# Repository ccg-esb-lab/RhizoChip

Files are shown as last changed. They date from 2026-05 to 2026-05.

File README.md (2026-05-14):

# RhizoChip

**RhizoChip: A modular 3D-printable in situ co-culture device for studying microbial interactions in soil and plant-associated systems**

## Overview

RhizoChip is a modular 3D-printable device designed for the controlled co-culture of microbial communities under laboratory and soil-associated conditions.

The device allows spatial confinement of microbial populations while enabling the exchange of diffusible metabolites through permeable membranes. This architecture supports the study of microbial interactions, community assembly, and the identification of functional consortia with potential applications in sustainable agriculture.

The design is implemented as a parametric OpenSCAD model, allowing users to modify the number of modules, rows, wells, dimensions, ports, and other structural features directly from code.

## Repository contents

- [`scad/`](scad/)  
  Parametric OpenSCAD design files used to generate the device geometry.

- [`stl/`](stl/)  
  Exported STL files for selected device configurations.

- [`docs/`](docs/)  
  Technical documentation describing the design, fabrication workflow, validation stage, and intended applications of the device.

## Documentation

The full technical report can be found in [`RhizoChip_TechnicalDocument.pdf`](./docs/RhizoChip_TechnicalDocument.pdf).

## Authors

Systems Biology Lab, Center for Genomic Sciences, UNAM.
Carles Tardío Pi and Rafael Peña-Miller.

## License

This project is licensed under the MIT License for code and documentation. Hardware design files are licensed under the CERN Open Hardware License. See the [`license.txt`](license.txt) file for details.

## Acknowledgements

We thank past and present members of the Systems and Synthetic Biology laboratories at CCG-UNAM for their input, discussion, and experimental support.

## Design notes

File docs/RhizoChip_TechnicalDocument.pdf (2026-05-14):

# RhizoChip // Technical Documentation

Version: 0.1
Last updated: May 2026
Contributors: RhizoChip is developed by the Systems Biology Program at the Center for Genomic Sciences, UNAM, as part of an effort to build reproducible, open, and modular experimental pipelines for microbial ecology and experimental evolution.
Development: Carles Tardío Pi (tardiopi@ccg.unam.mx), Rafael Peña Miller (rpm@ccg.unam.mx) Experimental users and contributors: Nicole Gomez, Gustavo Cuaxinque, Andrés López, Esperanza Martinez, Ayari Fuentes

License: RhizoChip is intended as an open research tool. Unless stated otherwise, the source code is distributed under the MIT License. The documentation, diagrams, and written material are distributed under a Creative Commons Attribution 4.0 International License (CC BY 4.0). Users may use, modify, and redistribute the code and documentation, provided that appropriate credit is given to the original contributors.

## 1. Overview

This device is a modular experimental platform designed for the controlled co-culture of microbial communities under laboratory and environmentally relevant conditions. The system enables the spatial confinement of microbial populations while allowing the exchange of diffusible metabolites and chemical signals through permeable membranes. It is intended for the study of microbial interactions, community assembly, and functional performance of synthetic microbial consortia, with a particular focus on soil and plant-associated microbiomes.

The platform is being developed as a tool to support the identification and optimization of microbial consortia with potential applications in sustainable agriculture, including biofertilization, plant growth promotion, and soil health improvement.

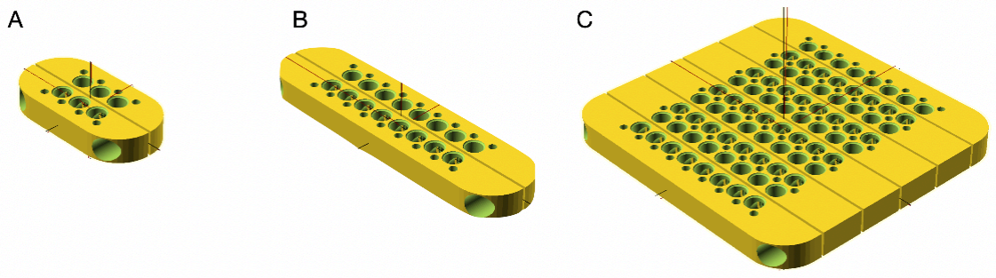
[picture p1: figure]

Figure 1. Modular architecture of the microbial co-culture device.
(A) 3D render of a miniaturized configuration with two modules and three rows of paired compartments.
(B) 3D render of a two-module configuration containing eight pairs of connected wells, designed for parallel co-culture assays. (C) 3D render of an expanded modular configuration composed of five paired module sets, each containing eight rows, illustrating the scalability of the device for larger experimental designs.

## 2. Design Principle

The device consists of modular rows of compartments that can be connected in paired configurations (Figure 1). Each compartment is designed to contain a microbial isolate or a defined microbial community. Adjacent compartments are separated by permeable membranes, allowing the diffusion of metabolites and chemical signals while preventing direct physical mixing of populations.

This architecture enables controlled comparison between connected and isolated configurations. In this way, the system can distinguish interaction-mediated effects from autonomous growth dynamics.

The design is implemented as a parametric OpenSCAD model, which allows the geometry of the device to be modified directly from code. Key parameters include the number of modules, number of rows and columns, module dimensions, well diameter, well spacing, lateral ports, screw holes, rod channels, lid geometry, and label placement. This makes the platform adaptable to different experimental scales, from small interaction assays to larger multi-module screens.

The modular design supports several experimental configurations, including:

- paired compartments for testing direct interaction effects
- multiple connected rows for higher-throughput interaction screening
- isolated rows as non-interaction controls
- expanded multi-block systems for larger community designs
- separate body and lid components for assembly, containment, and handling

## 3. Fabrication and Digital Design Workflow

The device is generated from a parametric OpenSCAD script. The code produces the 3D geometry of the device body and lid, and allows users to select between different configurations by editing the parameter block at the beginning of the file. For example, the user can define the number of modules, the number of rows, the number of columns, and the overall module dimensions.

The script includes predefined configurations, such as compact two-module devices, larger two-module devices with multiple rows, and multi-module layouts. The user can also define custom geometries by modifying the relevant parameters. The model includes integrated features for wells, lateral ports, vertical screw holes, horizontal rod channels, rounded module edges, and engraved labels.

A typical workflow is:

1. Open the .scad file in OpenSCAD.
2. Select whether to render the body or the lid using the render_body and render_lid variables.
3. Choose or modify the desired device configuration by setting parameters such as N, nrows, ncols, module_length, and module_width.
4. Preview and render the model.
5. Export the resulting geometry as an STL file.
6. Slice the STL file using standard 3D-printing software.
7. Fabricate the component using extrusion-based 3D printing.

Initial prototypes have been fabricated using 3D printing, primarily through extrusion-based additive manufacturing (Figure 2). This approach enables rapid prototyping, iterative design modifications, and low-cost production of custom geometries.

The current designs include devices fabricated in PLA and PC. Future optimization will focus on material compatibility with soil conditions, mechanical stability, sterilization procedures, membrane integration, and reproducibility across printing batches. The same digital design workflow can be adapted to other materials or manufacturing methods depending on the intended application and required robustness.

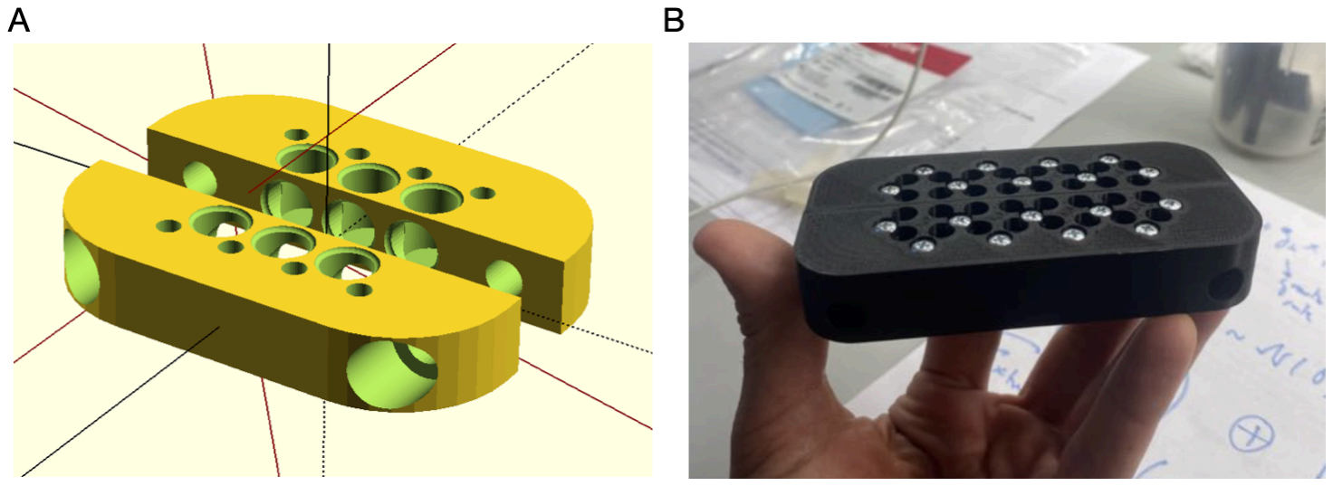
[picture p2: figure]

Figure 2. Design and fabrication of the microbial co-culture device.
(A) 3D render of a module with three compartments connected in paired configurations, allowing metabolite exchange between adjacent units. (B) Prototype of the device fabricated by 3D printing.

## 4. Experimental Use

The device is designed for use in several experimental contexts:

1. Laboratory experiments
The system can be inoculated with defined microbial communities and incubated under controlled conditions to evaluate containment, reproducibility, and metabolite-mediated interactions.
2. Controlled soil or mesocosm assays
The device can be placed in soil-like environments, compost, or pot systems to assess microbial growth and interaction dynamics under more complex physicochemical conditions.
3. In situ agricultural testing
The device can be deployed directly in agricultural soils to evaluate microbial interactions under field-relevant conditions.

In ongoing pilot work, the device has been used with synthetic microbial communities derived from bean root-associated microbiomes. These communities are being evaluated for their potential to assemble, interact, and support functions relevant to plant productivity.

## 5. Functional Validation

The device has been evaluated through a series of validation steps designed to test its performance under controlled experimental conditions. These include:

- confirmation of physical containment between compartments
- assessment of membrane-mediated exchange
- evaluation of microbial growth inside the device
- comparison between connected and isolated configurations
- reproducibility across device replicates
- recovery of microbial samples after incubation
- functional testing of assembled consortia in plant-associated assays

Physical containment was evaluated through contamination-control experiments in which the device was exposed to external bacterial cultures while monitoring whether the internal compartments remained uncontaminated. These assays confirmed that the device maintains physical separation between populations while allowing controlled experimental handling (Figure 3).

Microbial growth and recovery were tested using defined microbial communities, including synthetic communities derived from bean root-associated microbiota. These experiments demonstrated that the device supports microbial incubation and downstream recovery of samples for analysis.

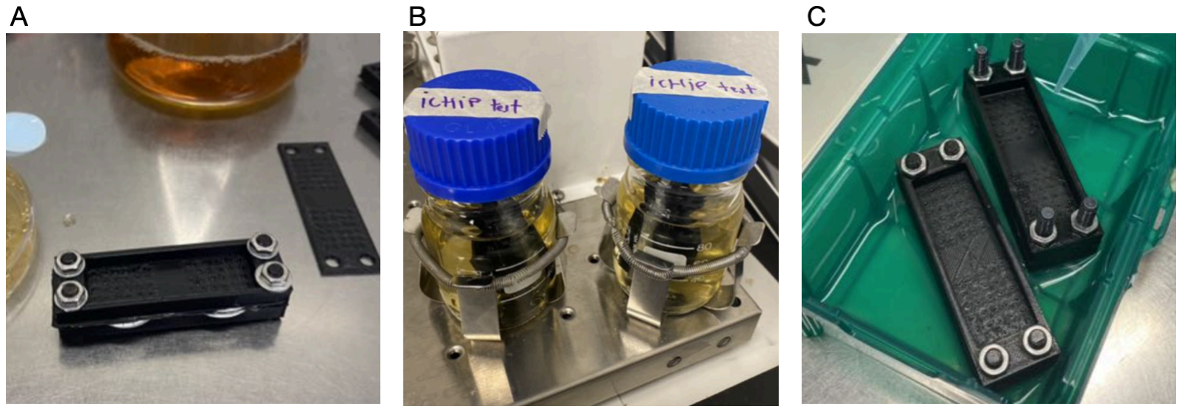
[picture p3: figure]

Figure 3. Validation of the device under controlled laboratory conditions.
(A) Co-culture device inoculated with a synthetic community derived from bean roots, composed of seven strains.
(B) Co-culture device inoculated with the same seven-strain synthetic community, used to evaluate system performance under controlled conditions. (C) Containment test in which the device was exposed to culture medium containing external bacteria. No internal contamination was observed, demonstrating physical isolation between compartments.

Functional validation is currently in progress through plant-associated assays in which assembled microbial communities are being evaluated for their effects on relevant plant phenotypes, including nodulation and growth-associated responses. This ongoing work is intended to assess the capacity of the platform to link microbial community structure and interaction patterns with functional outcomes in plant-associated systems.

## 6. Analytical Framework

The device generates quantitative data that can be used to infer microbial interactions. Growth, abundance, community composition, and functional readouts can be compared across experimental configurations.

Data analysis may include:

- comparison of growth in connected versus isolated compartments,
- inference of positive, negative, or neutral interactions,
- identification of stable consortia,
- detection of community-level functional effects,
- integration with ecological models or network inference methods.

The device is therefore not only a culture platform, but also part of an integrated experimental workflow for studying microbial interaction networks.

## 7. Technological Relevance

The platform addresses a current limitation in microbial ecology and agricultural biotechnology: the lack of experimental systems that connect controlled co-culture assays with environmentally relevant soil conditions. Existing in situ cultivation tools, such as iChip-like devices, have been useful for recovering previously uncultivable microorganisms, but are not primarily designed to quantify interaction networks among defined microbial communities.

This device aims to bridge that gap by combining:

- spatial confinement,
- controlled metabolite exchange,
- modular experimental design,
- compatibility with synthetic communities,
- potential deployment in soil or agricultural environments.

## 8. Development Stage

The current state of development corresponds to an intermediate technology readiness level, between TRL 4 and TRL 6. The system has been designed, fabricated, and tested as a functional prototype under laboratory conditions, demonstrating the basic operation of the co-culture architecture and the integration of its main components.

Current work focuses on advancing the platform from laboratory validation toward demonstration in relevant agricultural environments. This includes improving material selection, reproducibility, structural robustness, membrane integration, and performance under soil-associated conditions.

The next development phase will support the transition from TRL 4, corresponding to validation of an integrated prototype in the laboratory, toward TRL 6, corresponding to demonstration of the system in relevant agricultural settings. This will involve testing the device in controlled soil systems, mesocosms, and field-like conditions to evaluate its performance, reliability, and capacity to generate reproducible data on microbial interactions in soil.

## 9. Intended Applications

Potential applications include:

- identification of microbial consortia for sustainable agriculture,
- screening of plant-associated microbial communities,
- evaluation of biofertilizer or bioprotective formulations,
- study of microbial interaction networks in soil,
- development of microbiome-based agricultural technologies,
- experimental validation of synthetic microbial communities.

## 10. Conclusion

The in situ microbial co-culture device provides a modular and adaptable platform for studying microbial interactions under controlled and environmentally relevant conditions. By enabling spatial confinement and metabolite exchange, the system supports the quantitative analysis of microbial interactions and the identification of functional consortia.

Its development has potential relevance for agricultural biotechnology, particularly for the rational design and validation of microbial consortia aimed at improving productivity and sustainability in agricultural systems.

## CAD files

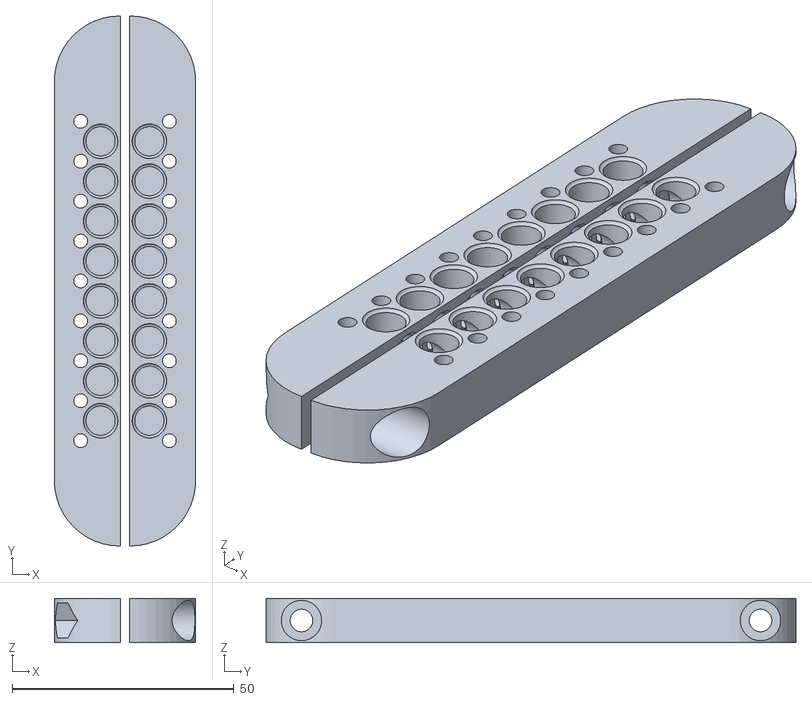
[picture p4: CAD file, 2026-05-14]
stl/RhizoChip.stl
31.9 x 119.5 x 10.0

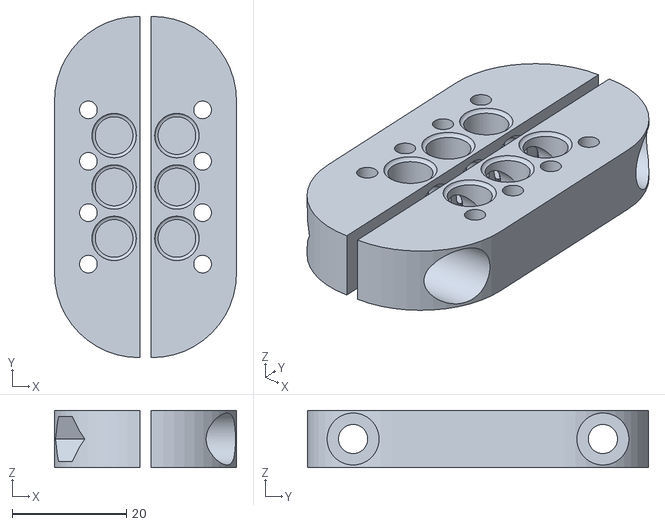
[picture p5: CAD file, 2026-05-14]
stl/RhizoChip_mini.stl
31.9 x 59.8 x 10.0

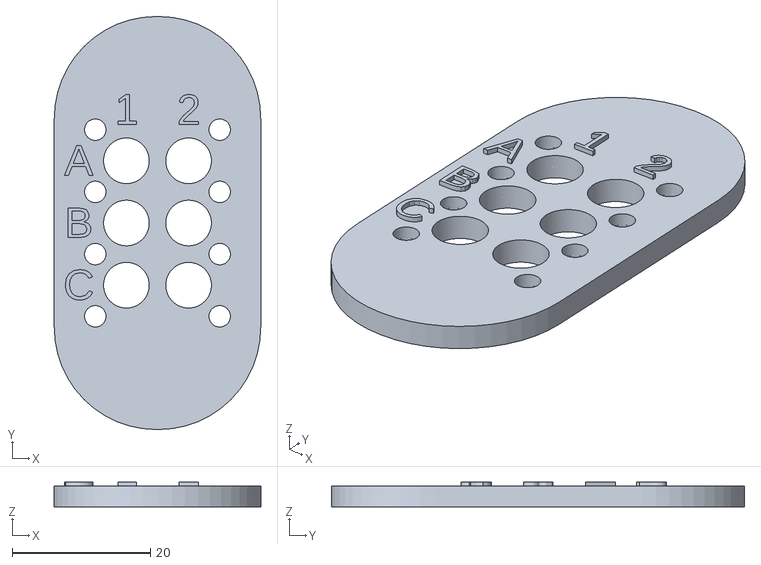
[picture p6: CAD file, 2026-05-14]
stl/RhizoChip_mini_lid.stl
29.9 x 59.8 x 3.61

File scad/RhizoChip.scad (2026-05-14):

// -----------------------------------------------------------------------------
// RhizoChip: Modular co-culture device generator
// -----------------------------------------------------------------------------
// Parametric OpenSCAD design for modular microbial co-culture devices.
// The model includes configurable module size, well layout, lateral ports,
// fastening features, lids, and label placement.
//
// Developed by ESB / Center for Genomic Sciences, UNAM
//
// This code is released under the MIT License.
// See the LICENSE file distributed with this source code for details.
//--------------------------------------------
// PRINTING / RENDER PARAMETERS
//--------------------------------------------

render_body = false;
render_lid  = true;

gap = 0.0;
fn  = 48;

//--------------------------------------------
// ARRAY / DEVICE CONFIGURATION
//--------------------------------------------

plate_length = 119.5;

// Version: Bimodule mini (2-cols, 3 rows)
/*
N = 2;      // Number of modules
nrows = 3;  // Number of rows
ncols = 2;  // Number of columns
module_length=plate_length/2;
module_width=plate_length/4/2;
label_margin_top  = 13.5;
*/

// Version: Bimodule (2-cols, 8 rows)

N = 2;      // Number of modules
nrows = 8;  // Number of rows
ncols = 2;  // Number of columns
module_length=plate_length;
module_width=plate_length/4/2;
label_margin_top  = 20;


// Version: Multimodule (2-cols, 8 rows)
/*
N = 6;      // Number of modules
nrows = 8;  // Number of rows
ncols = 2;  // Number of columns
module_length=plate_length;
module_width=18;
label_margin_top  = 20;
*/

// Version: Multimodule mini (2-cols, 3 rows)
/*
N = 4;      // Number of modules
nrows = 5;  // Number of rows
ncols = 2;  // Number of columns
module_length=18.4*4;
module_width=18.4;
label_margin_top  = 10;
*/

//--------------------------------------------
// MODULE DIMENSIONS
//--------------------------------------------


module_h   = 10;   // Body height (mm)
lid_h     = 3;    // Lid height (mm)
bottom_th = 1.2;  // Solid bottom thickness (mm)

//--------------------------------------------
// WELL GRID
//--------------------------------------------

pitch_x = 9.0;  // Well pitch along X (mm)
pitch_y = 9.0;  // Well pitch along Y (mm)

//--------------------------------------------
// WELL GEOMETRY
//--------------------------------------------

well_d = 6.6;       // Well diameter (mm)
well_r = well_d/2;  // Well radius (mm)

label_margin_left = 3.5;

//--------------------------------------------
// HARDWARE GEOMETRY
//--------------------------------------------

r_oring = 0.6;   // O-ring radius (mm)
r_screw = 1.55;  // Vertical screw hole radius (mm)
r_rod   = 2.55;  // Horizontal rod radius (mm)

h_bolt        = 12.5;   // Bolt head recess height (mm)
h_bolt_bottom = -0.01;  // Bottom bolt recess height (mm)
r_bolt_bottom = 3.2;    // Bottom bolt-hole radius (mm)

d_rod      = 8.0;   // Rod offset from edge (mm)
r_rod_bolt = 4.55;  // Rod bolt radius (mm)


//--------------------------------------------
// ROUNDING / CORNER GEOMETRY
//--------------------------------------------

corner_r = 14.75;
box_padding = 20.0;
diameter_round = (module_length + box_padding) / 3.372;
corner_d       = (module_length + box_padding) / 3.372;

//--------------------------------------------
// DEFAULT ALIASES FOR MODULE PARAMETERS
//--------------------------------------------

default_gap      = gap;
default_fn       = fn;

default_corner_d = corner_d;
default_corner_r = corner_r;

// DEFAULT HARDWARE PARAMETERS
default_r_rod     = r_rod;
default_d_rod     = d_rod;
default_r_bolt    = r_bolt_bottom;
default_h_bolt    = h_bolt;
default_r_screw   = r_screw;

default_slop      = 2;
default_fn_bolt   = 6;

// DEFAULT WELL GRID PARAMETERS
default_rows      = nrows;
default_cols      = ncols;
default_pitch_x   = pitch_x;
default_pitch_y   = pitch_y;
default_r_well    = well_r;
default_bottom_th = bottom_th;
default_lid_depth = 1;

// DEFAULT LABEL PARAMETERS
default_label_font  = "Liberation Sans";
default_label_size  = 0.5 * default_pitch_y;
default_label_depth = 0.6;
default_margin_left = label_margin_left; 
default_label_margin_top  = label_margin_top;

//--------------------------------------------
// MODEL ASSEMBLY
//--------------------------------------------

if (render_body) {

    stack_modules_with_cuts(
        n         = N,
        L         = module_width,
        W         = module_length,
        H         = module_h,
        gap       = default_gap,
        total_len = undef,

        corner_d  = default_corner_d,
        corner_r  = default_corner_r,

        // Subtractive features enabled for the body.
        cut_rods     = true,
        cut_vertical = true,
        cut_wells    = true,
        cut_lateral  = true,

        r_rod = default_r_rod,
        d_rod = default_d_rod,

        r_bolt = default_r_bolt,
        h_bolt = default_h_bolt,

        r_screw = default_r_screw,

        y_offsets = [
            0,
            module_length/2 - 7,
            -module_length/2 + 7
        ],

        rows    = default_rows,
        cols    = default_cols,
        pitch_x = default_pitch_x,
        pitch_y = default_pitch_y,

        r_well    = default_r_well,
        bottom_th = default_bottom_th,

        lateral_side = "both"
    );
}


if (render_lid) {

    translate([0, 0, module_h - lid_h + 10]) {

        stack_modules_with_cuts(
            n         = N,
            L         = module_width,
            W         = module_length,
            H         = lid_h,
            gap       = default_gap,
            total_len = undef,

            corner_d  = default_corner_d,
            corner_r  = default_corner_r,

            // Subtractive features enabled for the lid.
            cut_rods     = false,
            cut_vertical = true,
            cut_wells    = true,
            cut_lateral  = false,

            lid        = true,
            cut_labels = true,
            start_col  = 1,

            r_rod = default_r_rod,
            d_rod = default_d_rod,

            r_bolt = default_r_bolt,
            h_bolt = default_h_bolt,

            r_screw = default_r_screw,

            rows    = default_rows,
            cols    = default_cols,
            pitch_x = default_pitch_x,
            pitch_y = default_pitch_y,

            r_well    = default_r_well,
            bottom_th = -1,

            lateral_side = "both",

            label_font  = default_label_font,
            label_size  = default_label_size,
            label_depth = default_label_depth,

            margin_left = default_margin_left,
            label_margin_top  = default_label_margin_top
        );
    }
}


//--------------------------------------------
// GEOMETRY HELPERS
//--------------------------------------------

// Torus using rotate_extrude.
// R: major radius; r: tube radius.
module torus(R = 30, r = 10, $fn = 20) {
    if (R <= r) {
        echo("Warning: Use R > r to avoid self-intersection.");
    }

    rotate_extrude($fn = $fn)
        translate([R, 0, 0])
            circle(r = r, $fn = $fn);
}

// Shift wells so the edge nearest the flat side is half a pitch from the edge.
// round_side: "left", "right", or "none".
function well_shift_half_pitch(L, cols, pitch_x, r_well, round_side) =
    let(
        grid_w     = (cols - 1)*pitch_x + 2*r_well,
        x0         = -grid_w/2 + r_well,
        x_last     = x0 + (cols - 1)*pitch_x,
        want_left  = -L/2 + pitch_x/2,
        want_right =  L/2 - pitch_x/2,
        s_left     = want_left - x0,
        s_right    = want_right - x_last
    )
    (round_side == "right") ? s_left :
    (round_side == "left")  ? s_right :
                               (s_left + s_right)/2;

// Shift used for each slice in the stacked assembly.
function dx_for_slice(side, L, cols_i, pitch_x, r_well) =
    let(
        grid_w = (cols_i - 1)*pitch_x + 2*r_well,
        x0     = -grid_w/2 + r_well,
        xlast  = x0 + (cols_i - 1)*pitch_x
    )
    (side == "right") ? (-L/2 + pitch_x/2 - x0) :
    (side == "left")  ? ( L/2 - pitch_x/2 - xlast) :
                         0;


//--------------------------------------------
// MODULE BODY
//--------------------------------------------

// L, W, H in mm.
// round_side: "none", "left", or "right".
module module_body(
    L,
    W,
    H,
    corner_d   = 0,
    corner_r   = 0,
    round_side = "none",
    fn         = fn
) {
    plate_padding = 0;

    d = min(corner_d, min(L, W) - 0.1);
    r = corner_r;

    module _slab(x, y, z) {
        cube([x, y, z], center = true);
    }

    module _bridge_right() {
        band = max(W - 2*r, 0);

        if (band > 0) {
            translate([L/2 - r/2, 0, 0])
                _slab(r, band + plate_padding, H);
        }
    }

    module _bridge_left() {
        band = max(W - 2*r, 0);

        if (band > 0) {
            translate([-L/2 + r/2, 0, 0])
                _slab(r, band + plate_padding, H);
        }
    }
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
